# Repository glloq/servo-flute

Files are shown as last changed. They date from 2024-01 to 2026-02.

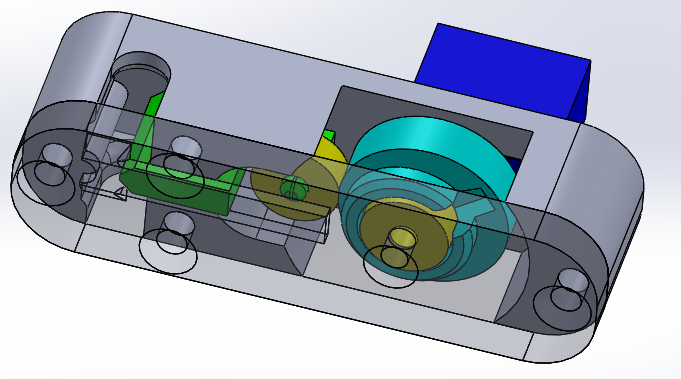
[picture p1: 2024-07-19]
img/servo vavle variable.png

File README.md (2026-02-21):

# Servo Flute V3 🎵

**Une flûte robotique contrôlée par MIDI avec support breath controller**





---

## 📋 Vue d'ensemble

La **Servo Flute V3** est un instrument robotique qui transforme des messages MIDI en sons de flûte acoustique. Utilisant des servomoteurs pour actionner les doigts et contrôler le débit d'air, elle offre un contrôle expressif comparable à une flûte jouée par un humain.

### Caractéristiques principales

- ✅ **Contrôle MIDI complet** - 8 Control Changes implémentés
- ✅ **Breath Controller (CC2)** - Contrôle dynamique du souffle en temps réel
- ✅ **Irish Flute 6 trous** - 14 notes jouables (A#5 - G7)
- ✅ **Vibrato optimisé** - sin() LUT pour CPU efficace
- ✅ **Watchdog timer** - Auto-restart en cas de blocage
- ✅ **Outil de calibration** - Interface Serial Monitor intuitive
- ✅ **Auto-calibration micro** - INMP441 I2S pour calibration airflow automatique
- ✅ **Documentation complète** - Architecture, MIDI, Configuration

---

## 🚀 Démarrage Rapide

### Matériel Requis
#### Electronique :
- un controleur tel que l'arduino leonardo ou micro et des cables de prototypage
- un module PCA9685
- 7 servomoteurs 9g bas de gamme (avec dent metalique) => 6 doigts et 1 servo air flow
- Alimentation 5V 5A minimum
- Un solenoide 5V/6V avec 2N min (ideal secutiré a 5N ) il faut viser 500mA maximum de consomation pour eviter la surchauffe (idéal autour de 300mA)
- un mofset adapté a la puissance
- une diode de roue libre
- un condensateur adapté
- (Optionnel) **Micro INMP441** I2S MEMS pour auto-calibration du debit d'air 
  
  #### Mécanique :
  
- un systeme de mousse a pores fermée environ 3mm d'epaisseur
- les doigts et supports imprimé en 3D
- servo valve imprimé en 3D avec 2 roulements 12x4x3 et 3vis/ecrous M3x20mm 
- une boite ou planche pour supportrer le tout 

## Premiere utilisation

#### Calibration 

avant de fixer les doigts, il faut que les servomoteur soit initialisé en position fermé a 90° 
Pour le servo AirFlow, il faut bien definir les 2 angles maximum de deplacement ( SERVO_VALVE_MIN_FLOW , SERVO_VALVE_MAX_FLOW ) en fonction du systeme utilisé

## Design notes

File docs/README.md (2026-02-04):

# Documentation Servo Flute V3

Bienvenue dans la documentation complète de la Servo Flute V3 - Une flûte robotique contrôlée par MIDI.

---

## 📚 Index de la Documentation

### 🏁 Démarrage

| Document | Description |
|---|---|
| **[README_V3.md](README_V3.md)** | Vue d'ensemble de la Servo Flute V3 |
| **[CONFIGURATION_GUIDE.md](CONFIGURATION_GUIDE.md)** | Guide de configuration complète |
| **[../Calibration_Tool/README.md](../Calibration_Tool/README.md)** | Guide d'utilisation de l'outil de calibration |

### 🏗️ Architecture et Code

| Document | Description |
|---|---|
| **[ARCHITECTURE.md](ARCHITECTURE.md)** | Architecture globale du système |
| | • Structure des classes |
| | • Flux de données |
| | • Organisation du code |
| | • Sécurité et robustesse |

### 🎹 MIDI et Contrôles

| Document | Description |
|---|---|
| **[MIDI_CC_IMPLEMENTATION.md](MIDI_CC_IMPLEMENTATION.md)** | Tous les Control Changes MIDI |
| | • CC1 (Modulation/Vibrato) |
| | • CC2 (Breath Controller) |
| | • CC7 (Volume) |
| | • CC11 (Expression) |
| | • CC74 (Brightness) |
| | • CC120, CC121, CC123 (Contrôles système) |
| | • Canal MIDI et rate limiting |
| **[CC2_BREATH_CONTROLLER.md](CC2_BREATH_CONTROLLER.md)** | CC2 Breath Controller détaillé |
| | • Fonctionnement technique |
| | • Configuration |
| | • Lissage, courbe exponentielle |
| | • Cas d'usage |
| | • Dépannage |

### ⚙️ Optimisations et Techniques

| Document | Description |
|---|---|
| **[SOLENOID_PWM.md](SOLENOID_PWM.md)** | Contrôle PWM du solénoïde |
| | • PWM activation + maintien |
| | • Réduction consommation |
| | • Durée de vie prolongée |
| **[VALVE_OPTIMIZATION.md](VALVE_OPTIMIZATION.md)** | Optimisation de la valve pneumatique |
| | • Temps de réponse |
| | • Gestion transitions |
| **[TIMING_ANTICIPATION.md](TIMING_ANTICIPATION.md)** | Timing et anticipation mécanique |
| | • Anticipation doigts |
| | • Séquençage événements |
| | • Legato et staccato |

### 🎼 Instruments

| Document | Description |
|---|---|
| **[INSTRUMENTS_GUIDE.md](INSTRUMENTS_GUIDE.md)** | Guide pour différents instruments |
| | • Irish Flute (6 trous) |
| | • Flûte à bec |
| | • Adaptation personnalisée |

---

## 🎯 Parcours Recommandés

### Pour débutant (première utilisation)

1. **[README_V3.md](README_V3.md)** - Comprendre le projet
2. **[CONFIGURATION_GUIDE.md](CONFIGURATION_GUIDE.md)** - Configuration matérielle
3. **[../Calibration_Tool/README.md](../Calibration_Tool/README.md)** - Calibrer l'instrument
4. **[MIDI_CC_IMPLEMENTATION.md](MIDI_CC_IMPLEMENTATION.md)** - Découvrir les contrôles MIDI

### Pour développeur (comprendre le code)

1. **[ARCHITECTURE.md](ARCHITECTURE.md)** - Structure globale
2. **[MIDI_CC_IMPLEMENTATION.md](MIDI_CC_IMPLEMENTATION.md)** - Implémentation MIDI
3. **[CC2_BREATH_CONTROLLER.md](CC2_BREATH_CONTROLLER.md)** - Feature avancée CC2
4. **[TIMING_ANTICIPATION.md](TIMING_ANTICIPATION.md)** - Timing précis

### Pour musicien (utilisation avancée)

1. **[MIDI_CC_IMPLEMENTATION.md](MIDI_CC_IMPLEMENTATION.md)** - Tous les contrôles MIDI
2. **[CC2_BREATH_CONTROLLER.md](CC2_BREATH_CONTROLLER.md)** - Breath controller physique
3. **[INSTRUMENTS_GUIDE.md](INSTRUMENTS_GUIDE.md)** - Adapter à votre instrument

### Pour optimisation et troubleshooting

1. **[SOLENOID_PWM.md](SOLENOID_PWM.md)** - Optimisation solénoïde
2. **[VALVE_OPTIMIZATION.md](VALVE_OPTIMIZATION.md)** - Optimisation valve
3. **[TIMING_ANTICIPATION.md](TIMING_ANTICIPATION.md)** - Réglages timing

---

## 🔧 Configuration Actuelle

**Instrument :** Irish Flute 6 trous
**Tonalité :** C majeur
**Notes jouables :** 14 (A#5 - G7)
**Servos doigts :** 6
**Canal MIDI :** Omni (0) - Écoute tous les canaux

---

## 🎵 Features MIDI Implémentées

### Control Changes (CC)

- ✅ **CC1** - Modulation (Vibrato)
- ✅ **CC2** - Breath Controller (Contrôle dynamique souffle)
- ✅ **CC7** - Volume (Réduction limite haute)
- ✅ **CC11** - Expression (Nuances dynamiques)
- ✅ **CC74** - Brightness (Stocké, usage futur)
- ✅ **CC120** - All Sound Off (Arrêt urgence)
- ✅ **CC121** - Reset All Controllers
- ✅ **CC123** - All Notes Off

### Autres Features MIDI

- ✅ **Canal MIDI** : Omni mode (0) ou spécifique (1-16)
- ✅ **Rate Limiting** : 10 CC/sec général, 50 CC2/sec
- ✅ **Vibrato optimisé** : sin() LUT 256 entrées
- ❌ **Pitch Bend** : Retiré (logique incorrecte)

---

## 📊 Ordre d'Application des Contrôles

```
CC7 (Volume) → CC2 (Breath) OU Velocity → CC11 (Expression) → CC1 (Vibrato)
      ↓                 ↓                        ↓                   ↓
 Réduit plage      Source airflow           Nuances dans      Oscillation
 haute globale     (choix prioritaire)      plage réduite     autour angle
```

**Détails :** Voir [MIDI_CC_IMPLEMENTATION.md](MIDI_CC_IMPLEMENTATION.md)

---

## 🛠️ Outils Disponibles

### Calibration Tool

**Emplacement :** `/Calibration_Tool/`

**Fonction :** Calibration interactive via Serial Monitor

**Workflow :**
1. Calibrer servos doigts (angle + direction)
2. Calibrer notes (airflowMin% + airflowMax%)
3. Générer code C++ formaté
4. Copier-coller dans `settings.h`

**Documentation :** [../Calibration_Tool/README.md](../Calibration_Tool/README.md)

---

## 🔒 Sécurité

### Watchdog Timer
- **Timeout :** 4 secondes
- **Fonction :** Auto-restart si code bloqué
- **Implémentation :** `wdt_enable(WDTO_4S)` + `wdt_reset()` dans loop

### État Sûr (initSafeState)
- **Appelé :** Au démarrage AVANT toute initialisation
- **Actions :** Solénoïde fermé, airflow repos, doigts fermés
- **Protection :** Crash, reset, power-on

### Rate Limiting
- **CC général :** 10 messages/sec
- **CC2 (Breath) :** 50 messages/sec
- **Exemptions :** CC 120, 121, 123 (urgence)

---

## 📈 Historique des Versions

### V3 (Actuelle)

**Date :** 2026-01-25 à 2026-02-04

**Features majeures :**
- ✅ Control Changes MIDI complets (8 CC)
- ✅ CC2 Breath Controller (contrôle souffle dynamique)
- ✅ Nouvelle logique CC7→CC2→CC11
- ✅ Rate limiting configurableble
- ✅ Canal MIDI (omni + spécifique)
- ✅ Vibrato optimisé (sin LUT)
- ✅ Watchdog timer + état sûr
- ✅ Configuration Irish Flute 6 trous
- ✅ Outil calibration standalone

**Commits principaux :**
- `CC2 Breath Controller : Contrôle dynamique souffle` (2026-02-04)
- `Suppression Pitch Bend : Logique incorrecte retirée` (2026-02-04)
- `Nouvelle logique CC7/CC11 : Volume réduit plage avant Expression` (2026-02-04)
- `Améliorations MIDI : Canal, CC étendus, Rate Limiting` (2026-02-04)

---

## 🤝 Contribution

### Structure Documentation

**Principe :** Un document = Un sujet précis

**Organisation :**
```
docs/
├── README.md                      # Index (ce fichier)
├── ARCHITECTURE.md                # Architecture code
├── MIDI_CC_IMPLEMENTATION.md      # Control Changes généraux
├── CC2_BREATH_CONTROLLER.md       # CC2 spécifique (détaillé)
├── CONFIGURATION_GUIDE.md         # Configuration matérielle
├── INSTRUMENTS_GUIDE.md           # Adaptation instruments
├── SOLENOID_PWM.md                # Technique solénoïde
├── TIMING_ANTICIPATION.md         # Technique timing
├── VALVE_OPTIMIZATION.md          # Optimisation valve
└── README_V3.md                   # Vue d'ensemble V3
```

**Ajout de documentation :**
1. Créer document dans `/docs/`
2. Format Markdown
3. Mettre à jour cet index (README.md)
4. Commit avec message descriptif

---

## 📞 Support

**GitHub Repository :** [https://github.com/glloq/servo-flute](https://github.com/glloq/servo-flute)

**Issues :** Utiliser GitHub Issues pour :
- Bugs
- Questions
- Suggestions d'amélioration
- Demandes de documentation

---

**Créé le :** 2026-02-04
**Version Servo Flute :** V3
**Dernière mise à jour :** 2026-02-04

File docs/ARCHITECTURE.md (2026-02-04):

# Architecture Servo Flute V3

## 📋 Vue d'ensemble

La Servo Flute V3 est une flûte robotique contrôlée par MIDI, utilisant des servomoteurs pour actionner les doigts et contrôler le débit d'air. L'architecture est modulaire, séparant les responsabilités en classes spécialisées.

**Version :** V3
**Platform

e :** Arduino (ATmega32u4 - Leonardo/Micro)
**Date :** 2026-02-04

---

## 🏗️ Structure des dossiers

```
servo-flute/
├── Servo_flute_v3/           # Code principal Arduino
│   ├── Servo_flute_v3.ino    # Sketch principal
│   ├── settings.h            # Configuration (CENTRAL)
│   ├── MidiHandler.h/cpp     # Réception MIDI
│   ├── InstrumentManager.h/cpp  # Orchestration globale
│   ├── AirflowController.h/cpp  # Contrôle airflow + CC
│   ├── FingerController.h/cpp   # Contrôle doigts
│   ├── NoteSequencer.h/cpp      # Séquençage notes
│   └── EventQueue.h/cpp         # File d'événements MIDI
│
├── Calibration_Tool/         # Outil calibration standalone
│   ├── Calibration_Tool.ino
│   ├── settings_template.h
│   ├── CalibrationManager.h/cpp
│   ├── FingerCalibrator.h/cpp
│   ├── AirflowCalibrator.h/cpp
│   ├── OutputGenerator.h/cpp
│   └── README.md
│
├── docs/                     # Documentation
│   ├── ARCHITECTURE.md       # Ce fichier
│   ├── MIDI_CC_IMPLEMENTATION.md
│   ├── CC2_BREATH_CONTROLLER.md
│   ├── CONFIGURATION_GUIDE.md
│   ├── INSTRUMENTS_GUIDE.md
│   ├── SOLENOID_PWM.md
│   ├── TIMING_ANTICIPATION.md
│   ├── VALVE_OPTIMIZATION.md
│   └── README_V3.md
│
├── img/                      # Images
├── stl/                      # Fichiers STL (mécanique)
└── README.md                 # Documentation principale
```

---

## 🔧 Classes principales

### 1. **Servo_flute_v3.ino** - Sketch principal

**Rôle :** Point d'entrée, boucle principale, watchdog

**Responsabilités :**
- Initialisation matériel (`setup()`)
- Boucle principale (`loop()`)
- Watchdog timer (4s, auto-restart)
- État sûr en cas de crash (`initSafeState()`)

**Code clé :**
```cpp
void setup() {
  initSafeState();           // État sûr AVANT tout
  wdt_enable(WDTO_4S);       // Watchdog 4 secondes
  instrumentManager.begin(); // Initialiser tout
}

void loop() {
  wdt_reset();                      // Reset watchdog
  instrumentManager.processMidi();  // Traiter MIDI
  instrumentManager.update();       // Mise à jour contrôles
}
```

---

### 2. **settings.h** - Configuration centrale

**Rôle :** TOUTES les constantes du projet (un seul endroit)

**Sections :**
```cpp
// Hardware
#define NUMBER_SERVOS_FINGER 6
#define SERVO_FREQUENCY 50
#define SOLENOID_PIN 13

// Notes jouables (Irish flute 6 trous)
const NoteDefinition NOTES[] = { ... };

// MIDI
#define MIDI_CHANNEL 0
#define CC_RATE_LIMIT_PER_SECOND 10

// CC2 Breath Controller
#define CC2_ENABLED true
#define CC2_RATE_LIMIT_PER_SECOND 50
#define CC2_SMOOTHING_BUFFER_SIZE 5
// ...

// Vibrato
#define VIBRATO_FREQUENCY_HZ 6.0
#define VIBRATO_MAX_AMPLITUDE_DEG 8.0

// Debug
#define DEBUG 0
```

**Avantages :**
- Un seul fichier à modifier pour configuration
- Pas de magic numbers dans le code
- Facilite portage vers autres instruments

---

### 3. **MidiHandler** - Réception MIDI

**Rôle :** Écoute USB MIDI, filtre canaux, dispatch messages

**Fichiers :** `MidiHandler.h/cpp`

**Responsabilités :**
- Lire messages USB MIDI (`MIDIUSB.read()`)
- Filtrer par canal MIDI (omni ou spécifique)
- Parser messages (Note On/Off, CC, etc.)
- Déléguer à InstrumentManager

**Flux :**
```
USB MIDI → MidiHandler.processMidi()
              ↓
         isChannelAccepted()?
              ↓ (oui)
         Switch (messageType)
              ↓
    0x90 → instrument.noteOn()
    0x80 → instrument.noteOff()
    0xB0 → instrument.handleControlChange()
```

**Code clé :**
```cpp
void MidiHandler::processMidi() {
  midiEventPacket_t midiEvent = MidiUSB.read();

  byte channel = midiEvent.byte1 & 0x0F;
  if (!isChannelAccepted(channel)) return;  // Filtrage canal

  byte messageType = midiEvent.byte1 & 0xF0;

  switch (messageType) {
    case 0x90:  // Note On
      _instrument.noteOn(note, velocity);
      break;
    case 0xB0:  // Control Change
      _instrument.handleControlChange(ccNumber, ccValue);
      break;
  }
}
```

---

### 4. **InstrumentManager** - Chef d'orchestre

**Rôle :** Gestion globale, coordination entre tous les composants

**Fichiers :** `InstrumentManager.h/cpp`

**Responsabilités :**
- Initialiser tous les contrôleurs
- Gérer queue d'événements MIDI
- Gérer Control Changes (rate limiting, stockage)
- Coordonner FingerController + AirflowController + NoteSequencer
- Power management servos

**Sous-composants :**
```cpp
class InstrumentManager {
  Adafruit_PWMServoDriver _pwm;      // Driver PCA9685
  EventQueue _eventQueue;            // File MIDI
  FingerController _fingerCtrl;      // Contrôle doigts
  AirflowController _airflowCtrl;    // Contrôle airflow
  NoteSequencer _sequencer;          // Séquenceur

  // CC MIDI
  byte _ccVolume, _ccExpression, _ccModulation, _ccBreath, _ccBrightness;

  // Rate limiting
  uint16_t _ccCount, _cc2Count;
  unsigned long _ccWindowStart, _cc2WindowStart;
};
```

**Méthodes principales :**
```cpp
void begin();                              // Initialisation
void processMidi();                        // Traiter messages MIDI
void update();                             // Mise à jour continue
void noteOn(byte note, byte velocity);     // Note On
void noteOff(byte note);                   // Note Off
void handleControlChange(byte cc, byte val); // CC MIDI
void allSoundOff();                        // Urgence
void resetAllControllers();                // Reset CC
```

---

### 5. **AirflowController** - Contrôle du souffle

**Rôle :** Gérer servo airflow + solénoïde + tous les CC

**Fichiers :** `AirflowController.h/cpp`

**Responsabilités :**
- Positionner servo airflow selon note + velocity/CC2
- Contrôler solénoïde (ouverture/fermeture valve)
- Appliquer CC7 (Volume), CC2 (Breath), CC11 (Expression)
- Gérer vibrato (CC1)
- Lissage CC2 (buffer circulaire)
- Fallback velocity si CC2 absent

**Variables clés :**
```cpp
byte _ccVolume, _ccExpression, _ccModulation, _ccBreath;

// CC2 Breath Controller
byte _cc2SmoothingBuffer[5];
uint8_t _cc2BufferIndex, _cc2BufferCount;
unsigned long _lastCC2Time;
byte _lastVelocity;

// Vibrato
uint16_t _baseAngleWithoutVibrato;
bool _vibratoActive;
uint16_t _currentMinAngle, _currentMaxAngle;
```

**Méthodes principales :**
```cpp
void setAirflowForNote(byte note, byte velocity);  // Calcul angle note
void setCCValues(byte cc7, byte cc11, byte cc1);   // Mise à jour CC
void updateCC2Breath(byte cc2);                    // Recevoir CC2
void openSolenoid();                               // Ouvrir valve
void closeSolenoid();                              // Fermer valve
void update();                                     // Appliquer vibrato
```

**Ordre application (setAirflowForNote) :**
```
1. CC7 (Volume) → Réduit effectiveMaxAngle
2. CC2 (Breath) OU Velocity → Définit baseAngle
   - Si CC2 actif : moyenne lissée, courbe expo, seuil silence
   - Sinon : velocity classique
3. CC11 (Expression) → Module dans [minAngle, baseAngle]
4. Limiter bornes [SERVO_AIRFLOW_MIN, SERVO_AIRFLOW_MAX]
5. Stocker _baseAngleWithoutVibrato
6. CC1 (Vibrato) → Appliqué dans update() (continu)
```

---

### 6. **FingerController** - Contrôle des doigts

**Rôle :** Actionner servos doigts pour former les notes

**Fichiers :** `FingerController.h/cpp`

**Responsabilités :**
- Positionner servos doigts (ouvert/fermé)
- Gérer configuration par note (tableau NOTES[])
- Supporter inversion de sens servo

**Méthode principale :**
```cpp
void setFingersForNote(byte midiNote) {
  const NoteDefinition* note = getNoteByMidi(midiNote);

  for (int i = 0; i < NUMBER_SERVOS_FINGER; i++) {
    if (note->fingersClosed & (1 << i)) {
      // Doigt fermé
      setServoAngle(i, FINGERS[i].closedAngle);
    } else {
      // Doigt ouvert
      setServoAngle(i, FINGERS[i].openAngle);
    }
  }
}
```

**Configuration doigt (settings.h) :**
```cpp
const FingerDefinition FINGERS[] = {
  {0, 90, false},  // Servo 0: fermé=0°, ouvert=90°, pas inversé
  {0, 90, false},  // Servo 1
  {0, 90, false},  // Servo 2
  {0, 90, false},  // Servo 3
  {0, 90, false},  // Servo 4
  {0, 90, false}   // Servo 5
};
```

---

### 7. **NoteSequencer** - Séquençage temporel

**Rôle :** Gérer timing des événements, anticipation mécanique

**Fichiers :** `NoteSequencer.h/cpp`

**Responsabilités :**
- Anticiper mouvements mécaniques (doigts avant airflow)
- Gérer transitions entre notes (legato/staccato)
- Queue d'événements futurs
- Timing précis (ms)

**Constantes timing (settings.h) :**
```cpp
#define NOTE_ON_ANTICIPATION_TIME 30     // 30ms avant ouverture valve
#define NOTE_OFF_DELAY_TIME 10           // 10ms après fermeture valve
#define LEGATO_DELAY 20                  // 20ms pour legato
```

**Flux Note On :**
```
t=0ms   : noteOn() appelé
t=0ms   : Doigts positionnés
t=30ms  : Valve ouverte + Airflow activé  (anticipation)
```

**Flux Note Off :**
```
t=0ms   : noteOff() appelé
t=0ms   : Valve fermée + Airflow coupé
t=10ms  : Doigts libérés  (délai)
```

---

### 8. **EventQueue** - File d'événements

**Rôle :** Queue FIFO pour événements MIDI avec timestamp

**Fichiers :** `EventQueue.h/cpp`

**Structure :**
```cpp
struct Event {
  unsigned long timestamp;   // Quand exécuter (ms)
  byte type;                 // NOTE_ON, NOTE_OFF, etc.
  byte note;
  byte velocity;
};
```

**Méthodes :**
```cpp
bool push(Event event);       // Ajouter événement
bool pop(Event& event);       // Retirer événement
Event* peek();                // Voir prochain
bool isEmpty();
void clear();                 // Vider
```

---

## 🔄 Flux de données

### Flux complet Note On

```
1. USB MIDI Note On reçu
         ↓
2. MidiHandler.processMidi()
   - Lecture MIDIUSB.read()
   - Filtrage canal MIDI
         ↓
3. InstrumentManager.noteOn(note, velocity)
   - Ajouter événement à EventQueue
   - Timestamp = now + anticipation
         ↓
4. NoteSequencer.update() (dans loop)
   - Événement prêt ?
         ↓
5. FingerController.setFingersForNote(note)
   - Positionner servos doigts
         ↓
6. AirflowController.setAirflowForNote(note, velocity)
   - Calcul angle : CC7 → CC2/Velocity → CC11
   - Stocker _baseAngleWithoutVibrato
         ↓
7. AirflowController.openSolenoid()
   - Ouvrir valve pneumatique
         ↓
8. AirflowController.update() (continu dans loop)
   - Si CC1 > 0 : Appliquer vibrato
   - Sin() LUT pour oscillation
   - Limiter [_currentMinAngle, _currentMaxAngle]
```

### Flux Control Change (CC2 Breath)

```
1. USB MIDI CC2 reçu (valeur 0-127)
         ↓
2. MidiHandler.processMidi()
   - case 0xB0: Control Change
         ↓
3. InstrumentManager.handleControlChange(2, ccValue)
   - Rate limiting vérifié (50/sec max pour CC2)
         ↓
4. AirflowController.updateCC2Breath(ccValue)
   - Ajouter au buffer circulaire
   - Mise à jour _lastCC2Time
         ↓
5. Prochaine note jouée → setAirflowForNote()
   - Vérifier timeout CC2
   - Calculer moyenne lissée buffer
   - Appliquer courbe exponentielle
   - Vérifier seuil silence
   - Utiliser CC2 comme airflowSource (remplace velocity)
         ↓
6. Angle airflow calculé avec CC2 au lieu de velocity
```

---

## 🎛️ Configuration par instrument

### Irish Flute (6 trous) - Configuration actuelle

**settings.h :**
```cpp
#define NUMBER_SERVOS_FINGER 6

const NoteDefinition NOTES[] = {
  // midiNote, airflowMin%, airflowMax%, fingersBitmap
  {70,  20,  75, 0b111111},  // A#5 (tous fermés)
  {72,  20,  75, 0b111110},  // C6
  {73,  20,  75, 0b111100},  // C#6
  {74,  25,  70, 0b111000},  // D6
  {75,  25,  70, 0b110000},  // D#6
  {77,  25,  70, 0b100000},  // F6
  {78,  30,  65, 0b000000},  // F#6 (tous ouverts)
  // ... octave supérieur
  {91,  40,  55, 0b000000}   // G7
};
```

**Caractéristiques :**
- 6 servos doigts
- 14 notes jouables (A#5 - G7)
- Tonalité : C majeur
- Airflow : 20-75% (notes graves), 40-55% (notes aiguës)

### Adaptation pour autre instrument

**Exemple : Flûte à bec soprano (8 trous)**

```cpp
#define NUMBER_SERVOS_FINGER 8  // Au lieu de 6

const NoteDefinition NOTES[] = {
  {67,  15,  80, 0b11111111},  // G4 (tous fermés)
  {69,  15,  80, 0b11111110},  // A4
  // ... définir toutes les notes
  {86,  50,  60, 0b00000000}   // D6 (tous ouverts)
};

const FingerDefinition FINGERS[] = {
  {0, 90, false},  // 8 servos au lieu de 6
  {0, 90, false},
  {0, 90, false},
  {0, 90, false},
  {0, 90, false},
  {0, 90, false},
  {0, 90, false},
  {0, 90, false}
};
```

**Le code s'adapte automatiquement** grâce à `NUMBER_SERVOS_FINGER` !

---

## 🔒 Sécurité et robustesse

### 1. Watchdog Timer

**Problème :** Code bloqué (bug, boucle infinie) → Instrument mort

**Solution :** Watchdog 4 secondes auto-restart

```cpp
// setup()
wdt_enable(WDTO_4S);  // Watchdog 4 secondes

// loop()
wdt_reset();  // Reset à chaque itération
```

Si `loop()` ne s'exécute pas pendant 4s → Arduino redémarre automatiquement

### 2. État sûr (initSafeState)

**Problème :** Crash, reset, power-on → Servos position inconnue

**Solution :** État sûr AVANT tout

```cpp
void initSafeState() {
  // Fermer solénoïde
  digitalWrite(SOLENOID_PIN, LOW);

  // Airflow au repos
  pwm.setPWM(NUM_SERVO_AIRFLOW, 0, pulseWidthOff);

  // Tous doigts fermés
  for (int i = 0; i < NUMBER_SERVOS_FINGER; i++) {
    pwm.setPWM(i, 0, pulseWidthClosed);
  }
}
```

Appelé en **PREMIER** dans `setup()`, avant toute autre init.

### 3. Rate Limiting

**Problème :** Flood MIDI → Saturation CPU, jitter servos

**Solution :** Limite 10 CC/sec (50 CC2/sec)

```cpp
if (_ccCount > CC_RATE_LIMIT_PER_SECOND) {
  return;  // Ignorer message
}
```

Messages urgents (CC 120, 121, 123) exemptés.

### 4. Validation entrées

**Problème :** Valeurs MIDI invalides (>127, négatives)

**Solution :** Validation systématique

```cpp
if (ccValue > 127) {
  if (DEBUG) Serial.println("ERREUR: CC invalide");
  return;  // Ignorer
}
```

### 5. Bornes servos

**Problème :** Angle calculé hors bornes physiques → Dommages mécanique

**Solution :** Clamp systématique

```cpp
if (finalAngle < SERVO_AIRFLOW_MIN) finalAngle = SERVO_AIRFLOW_MIN;
if (finalAngle > SERVO_AIRFLOW_MAX) finalAngle = SERVO_AIRFLOW_MAX;
```

Garanti servo toujours dans plage valide.

---

## 📊 Performance

### Temps de réponse

| Événement | Latence | Note |
|---|---|---|
| Note On → Doigts positionnés | < 5ms | Instantané |
| Note On → Valve ouverte | 30ms | Anticipation intentionnelle |
| CC2 reçu → Airflow ajusté | < 2ms | Très réactif |
| Vibrato update | 1ms | Continu (loop) |

### Charge CPU

| Tâche | CPU | Note |
|---|-----|---|
| Loop principale | ~20% | Léger |
| Rate limiting | < 1% | Négligeable |
| CC2 lissage | ~2% | Buffer moyennage |
| Vibrato sin() LUT | < 1% | Optimisé PROGMEM |
| **Total** | **~25%** | **Marge confortable** |

### Optimisations

1. **Sin() Lookup Table** : 256 entrées PROGMEM → 25x plus rapide que `sin()`
2. **Rate limiting** : Évite surcharge inutile
3. **Buffer circulaire CC2** : Moyenne glissante efficace
4. **Anticipation mécanique** : Masque latence doigts

---

## 🛠️ Outils de développement

### Calibration Tool

**Emplacement :** `/Calibration_Tool/`

**Rôle :** Calibrer servos doigts + airflow par note

**Workflow :**
1. Lancer `Calibration_Tool.ino`
2. Calibrer servos (angle fermé + ouvert)
3. Calibrer notes (airflowMin% + airflowMax%)
4. Générer code C++ formaté
5. Copier-coller dans `settings.h`

**Avantages :**
- Interface Serial Monitor intuitive
- Génère code prêt à l'emploi
- Évite erreurs manuelles

**Documentation :** Voir `/Calibration_Tool/README.md`

---

## 📚 Documentation associée

- **[MIDI_CC_IMPLEMENTATION.md](MIDI_CC_IMPLEMENTATION.md)** - Tous les Control Changes
- **[CC2_BREATH_CONTROLLER.md](CC2_BREATH_CONTROLLER.md)** - CC2 Breath Controller détaillé
- **[CONFIGURATION_GUIDE.md](CONFIGURATION_GUIDE.md)** - Guide configuration complète
- **[INSTRUMENTS_GUIDE.md](INSTRUMENTS_GUIDE.md)** - Adaptation autres instruments
- **[SOLENOID_PWM.md](SOLENOID_PWM.md)** - Contrôle PWM solénoïde
- **[TIMING_ANTICIPATION.md](TIMING_ANTICIPATION.md)** - Timing et anticipation
- **[VALVE_OPTIMIZATION.md](VALVE_OPTIMIZATION.md)** - Optimisation valve
- **[README_V3.md](README_V3.md)** - Vue d'ensemble V3

---

**Créé le :** 2026-02-04
**Version Servo Flute :** V3
**Statut :** ✅ Production

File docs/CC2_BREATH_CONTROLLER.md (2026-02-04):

# CC2 Breath Controller - Contrôle Dynamique du Souffle

## 📋 Vue d'ensemble

Le **CC2 (Breath Controller)** permet un contrôle dynamique et expressif du souffle en temps réel sur la servo-flute. Il remplace la velocity MIDI pour offrir un contrôle continu de l'airflow, transformant la servo-flute en véritable instrument à vent MIDI jouable avec un breath controller physique ou via automation DAW.

**Implémentation :** Option 1 - Remplacement Velocity
**Date d'implémentation :** 2026-02-04
**Statut :** ✅ Complet et fonctionnel

---

## 🎯 Qu'est-ce qu'un Breath Controller ?

### Définition

Un breath controller est un capteur de pression buccale qui convertit l'intensité du souffle d'un musicien en messages MIDI CC2 (valeurs 0-127). Il permet de contrôler des instruments MIDI comme on soufflerait dans un instrument à vent acoustique.

### Contrôleurs physiques compatibles

- **Yamaha BC3A / BC3** : Capteur de pression avec tube
- **TEControl BBC2** : Breath controller USB moderne
- **AKAI EWI / Yamaha WX5** : Wind controllers avec capteur intégré
- **Automation DAW** : Courbes de souffle dessinées (Ableton, Logic, etc.)

---

## 🔧 Fonctionnement Technique

### Principe de base

```
Musicien souffle → Capteur pression → CC2 MIDI (0-127) → Servo-flute → Airflow dynamique
```

**Différence avec Velocity :**
- **Velocity** : Fixe, définie au Note On (une seule valeur par note)
- **CC2** : Continu, envoyé en temps réel (20-100 msg/sec pendant la note)

### Ordre d'application

```
CC7 (Volume) → CC2 (Breath) OU Velocity → CC11 (Expression) → CC1 (Vibrato)
         ↓              ↓                        ↓                    ↓
   Réduit plage    Source airflow         Nuances dans      Oscillation
   haute globale   principale (choix)     plage réduite     autour angle
```

---

## ⚙️ Configuration (settings.h)

### Constantes disponibles

```cpp
/*******************************************************************************
--------------------  BREATH CONTROLLER (CC2) SETTINGS  ----------------------
******************************************************************************/

#define CC2_ENABLED true                  // Activer/désactiver CC2
#define CC2_RATE_LIMIT_PER_SECOND 50      // Max 50 CC2/sec (haute fréquence)
#define CC2_SILENCE_THRESHOLD 10          // CC2 < 10 → valve fermée
#define CC2_SMOOTHING_BUFFER_SIZE 5       // Buffer lissage (moyenne glissante)
#define CC2_RESPONSE_CURVE 1.4            // Courbe exponentielle (1.0-2.0)
#define CC2_TIMEOUT_MS 1000               // Timeout fallback velocity (ms)
```

### Paramètres expliqués

#### CC2_ENABLED
- **Type :** `true` / `false`
- **Défaut :** `true`
- **Effet :** Active ou désactive complètement le breath controller
- **Usage :** Mettre à `false` pour revenir au comportement velocity classique

#### CC2_RATE_LIMIT_PER_SECOND
- **Type :** Entier (1-100)
- **Défaut :** `50`
- **Effet :** Nombre maximum de messages CC2 traités par seconde
- **Recommandations :**
  - **30** : Automation DAW légère
  - **50** : Breath controller physique standard (défaut)
  - **100** : Breath controller haute performance (peut créer jitter)

#### CC2_SILENCE_THRESHOLD
- **Type :** Entier (0-127)
- **Défaut :** `10`
- **Effet :** Valeurs CC2 < seuil → considérées comme silence (valve fermée)
- **Recommandations :**
  - **5** : Seuil très bas (capte souffle très faible)
  - **10** : Seuil standard (défaut, évite bruits parasites)
  - **20** : Seuil élevé (nécessite souffle plus fort pour déclencher)

#### CC2_SMOOTHING_BUFFER_SIZE
- **Type :** Entier (1-10)
- **Défaut :** `5`
- **Effet :** Taille du buffer de lissage (moyenne glissante)
- **Recommandations :**
  - **3** : Lissage léger, réponse très rapide (peut avoir jitter)
  - **5** : Lissage standard (défaut, bon compromis)
  - **7-10** : Lissage fort, réponse plus lente mais très stable

#### CC2_RESPONSE_CURVE
- **Type :** Float (1.0-2.0)
- **Défaut :** `1.4`
- **Effet :** Courbe exponentielle appliquée : `CC2^valeur`
- **Comportement :**
  - **1.0** : Linéaire (pas de courbe)
  - **1.2-1.4** : Légèrement exponentiel (souffle faible = contrôle fin)
  - **1.5-1.8** : Très exponentiel (souffle faible = beaucoup de contrôle)
  - **2.0** : Quadratique (souffle faible = maximum de contrôle)

**Exemple courbe 1.4 :**
```
CC2 raw → Après courbe
10 → 6     (souffle faible = contrôle très fin)
50 → 35    (souffle moyen = contrôle progressif)
100 → 83   (souffle fort = puissance)
127 → 127  (souffle max = max)
```

#### CC2_TIMEOUT_MS
- **Type :** Entier (0-5000 ms)
- **Défaut :** `1000` (1 seconde)
- **Effet :** Temps sans CC2 avant fallback sur velocity
- **Recommandations :**
  - **0** : Pas de timeout (toujours CC2 si reçu, sinon velocity)
  - **500** : Timeout court (fallback rapide)
  - **1000** : Timeout standard (défaut)
  - **2000+** : Timeout long (breath controller temporairement inactif OK)

---

## 🎵 Fonctionnalités

### 1. Lissage (Smoothing)

**Problème :** Les breath controllers envoient des données très rapidement (50-100/sec) avec micro-variations → Jitter du servo

**Solution :** Buffer circulaire avec moyenne glissante

```cpp
// Buffer circulaire de 5 valeurs (défaut)
byte _cc2SmoothingBuffer[5] = {120, 122, 121, 123, 122};

// Calcul moyenne
smoothedCC2 = (120 + 122 + 121 + 123 + 122) / 5 = 121.6 ≈ 122

// Nouvelle valeur reçue (124) → Remplace la plus ancienne
_cc2SmoothingBuffer = {122, 121, 123, 122, 124};
smoothedCC2 = 122.4 ≈ 122
```

**Avantages :**
- Élimine les micro-variations
- Servo suit doucement les changements
- Pas de saccades mécaniques

### 2. Courbe Exponentielle

**Problème :** Relation linéaire CC2 → airflow peu naturelle

**Solution :** Courbe exponentielle `CC2^1.4`

```cpp
float normalizedCC2 = smoothedCC2 / 127.0;     // 0.0 - 1.0
float curvedCC2 = pow(normalizedCC2, 1.4);     // Courbe exponentielle
byte finalCC2 = curvedCC2 * 127;               // Retour 0-127
```

**Effet musical :**

| CC2 raw | Après courbe | Commentaire |
|---|---|---|
| 20 | 11 | Souffle faible = GRAND contrôle fin |
| 40 | 26 | Contrôle progressif |
| 60 | 43 | Zone intermédiaire |
| 80 | 62 | Souffle fort commence |
| 100 | 83 | Puissance |
| 127 | 127 | Maximum inchangé |

**Avantages :**
- Souffle faible → Contrôle très précis (nuances pianissimo)
- Souffle fort → Puissance directe (fortissimo)
- Comportement naturel comme une vraie flûte

### 3. Seuil de Silence

**Problème :** CC2 = 0-9 → Bruits parasites, souffle trop faible

**Solution :** Seuil à 10 (configurable)

```cpp
if (smoothedCC2 < CC2_SILENCE_THRESHOLD) {
  airflowSource = 0;                    // Silence
  setAirflowServoAngle(SERVO_AIRFLOW_OFF);
  closeSolenoid();                      // Fermer valve
  return;
}
```

**Avantages :**
- Pas de bruits parasites avec souffle très faible
- Silence franc (valve fermée)
- Comportement naturel : pas de souffle = pas de son

### 4. Fallback Velocity

**Problème :** Breath controller déconnecté/absent → Aucun son

**Solution :** Timeout automatique avec fallback sur velocity

```cpp
unsigned long timeSinceCC2 = millis() - _lastCC2Time;

if (CC2_TIMEOUT_MS > 0 && timeSinceCC2 > CC2_TIMEOUT_MS) {
  // Timeout : fallback sur velocity
  airflowSource = velocity;

  if (DEBUG) {
    Serial.print("DEBUG: CC2 timeout (");
    Serial.print(timeSinceCC2);
    Serial.print("ms) - Fallback velocity");
  }
}
```

**Avantages :**
- Fonctionne sans breath controller (utilise velocity classique)
- Transition automatique transparente
- Utile si breath controller temporairement inactif

### 5. Rate Limiting Séparé

**Problème :** CC2 haute fréquence (50/sec) vs autres CC (10/sec)

**Solution :** Rate limit séparé pour CC2

```cpp
// InstrumentManager.cpp
if (ccNumber == 2) {
  // Rate limiting CC2 : 50 msg/sec
  if (_cc2Count > CC2_RATE_LIMIT_PER_SECOND) {
    return;  // Ignorer
  }
} else {
  // Rate limiting autres CC : 10 msg/sec
  if (_ccCount > CC_RATE_LIMIT_PER_SECOND) {
    return;  // Ignorer
  }
}
```

**Avantages :**
- CC2 peut envoyer 50/sec (haute fréquence nécessaire)
- Autres CC limités à 10/sec (suffisant)
- Protection CPU optimale

---

## 🎹 Cas d'usage

### Cas 1 : Musicien avec breath controller physique

**Setup :**
```
Yamaha BC3 → USB-MIDI → DAW → Servo-flute
```

**Comportement :**
1. Musicien joue note C6 (Note On, velocity 100)
2. Velocity donne attaque initiale → Angle de base
3. Musicien commence à souffler → CC2 reçu (20/sec)
4. CC2 remplace velocity immédiatement
5. Musicien module souffle en temps réel :
   - Souffle faible (CC2 = 30) → Son doux, contrôle fin
   - Souffle moyen (CC2 = 70) → Son normal
   - Souffle fort (CC2 = 120) → Son puissant
6. Crescendo/diminuendo naturels par pression buccale

**Résultat :** La servo-flute répond exactement comme si le musicien soufflait dedans directement !

### Cas 2 : Automation DAW sans breath controller

**Setup :**
```
Ableton Live → Automation CC2 dessinée → Servo-flute
```

**Comportement :**
1. DAW envoie Note On + CC2 automatisé (courbe dessinée)
2. CC2 simule courbe de souffle réaliste :
   - Attaque : CC2 monte de 0 → 100 (0.1s)
   - Sustain : CC2 varie 90-110 (vibrations naturelles)
   - Release : CC2 descend de 100 → 0 (0.2s)
3. Servo suit précisément la courbe automatisée

**Résultat :** Performance enregistrée avec dynamique de souffle naturelle, impossible avec velocity seule.

### Cas 3 : Hybride (automation + live breath)

**Setup :**
```
DAW (CC7 + CC11 automation) + Musicien (CC2 breath live) → Servo-flute
```

**Comportement :**
1. DAW automatise :
   - CC7 : Volume global du morceau (fade in/out, variations section)
   - CC11 : Phrasé musical pré-enregistré (crescendos écrits)
2. Musicien contrôle en direct :
   - CC2 : Nuances en temps réel par souffle
3. Trois niveaux simultanés :
   - **CC7** = Structure globale (automation master)
   - **CC11** = Phrasé écrit (automation track)
   - **CC2** = Interprétation live (breath direct)

**Résultat :** Maximum d'expressivité - automation compositionnelle + interprétation performative !

---

## 🔬 Logique d'implémentation

### Flux de données

```
1. CC2 MIDI reçu (MidiHandler)
         ↓
2. InstrumentManager.handleControlChange(2, ccValue)
         ↓
3. Rate limiting vérifié (50/sec max)
         ↓
4. AirflowController.updateCC2Breath(ccValue)
         ↓
5. Ajout au buffer circulaire
         ↓
6. Timestamp mis à jour (_lastCC2Time)
         ↓
7. Note jouée → setAirflowForNote()
         ↓
8. Vérification timeout CC2
         ↓
9a. CC2 actif : Calcul moyenne lissée
         ↓
10a. Application courbe exponentielle
         ↓
11a. Vérification seuil silence
         ↓
12a. CC2 utilisé comme airflowSource

    OU

9b. CC2 timeout : Fallback velocity
         ↓
12b. Velocity utilisée comme airflowSource
         ↓
13. CC7 → airflowSource → CC11 → Vibrato
```

### Code simplifié

```cpp
// AirflowController.cpp - setAirflowForNote()

// 1. Calculer moyenne lissée CC2
uint16_t sum = 0;
for (uint8_t i = 0; i < _cc2BufferCount; i++) {
  sum += _cc2SmoothingBuffer[i];
}
byte smoothedCC2 = sum / _cc2BufferCount;

// 2. Seuil silence
if (smoothedCC2 < CC2_SILENCE_THRESHOLD) {
  airflowSource = 0;  // Silence
  closeSolenoid();
  return;
}

// 3. Courbe exponentielle
float normalizedCC2 = smoothedCC2 / 127.0;
float curvedCC2 = pow(normalizedCC2, CC2_RESPONSE_CURVE);
airflowSource = (byte)(curvedCC2 * 127);

// 4. Utiliser comme source airflow
baseAngle = map(airflowSource, 1, 127, minAngle, effectiveMaxAngle);
```

---

## 🎛️ Réglages Recommandés

### Pour breath controller physique (Yamaha BC3, TEControl)

```cpp
#define CC2_ENABLED true
#define CC2_RATE_LIMIT_PER_SECOND 50      // Haute fréquence
#define CC2_SILENCE_THRESHOLD 10          // Standard
#define CC2_SMOOTHING_BUFFER_SIZE 5       // Bon équilibre
#define CC2_RESPONSE_CURVE 1.4            // Naturel
#define CC2_TIMEOUT_MS 1000               // 1s avant fallback
```

### Pour automation DAW uniquement

```cpp
#define CC2_ENABLED true
#define CC2_RATE_LIMIT_PER_SECOND 30      // Fréquence modérée OK
#define CC2_SILENCE_THRESHOLD 5           // Plus sensible
#define CC2_SMOOTHING_BUFFER_SIZE 3       // Moins de lissage
#define CC2_RESPONSE_CURVE 1.2            // Courbe légère
#define CC2_TIMEOUT_MS 0                  // Pas de timeout
```

### Pour désactiver CC2 (velocity classique)

```cpp
#define CC2_ENABLED false                 // Désactivé
// Les autres paramètres sont ignorés
```

---

## 📊 Comparaison avec Velocity

| Aspect | Velocity | CC2 Breath Controller |
|---|---|---|
| **Fréquence** | 1 fois (Note On) | Continue (20-100/sec) |
| **Contrôle** | Statique | Dynamique temps réel |
| **Expressivité** | Fixe par note | Crescendo/diminuendo en cours |
| **Naturel flûte** | Approximation | Simulation exacte |
| **Matériel** | Clavier MIDI standard | Breath controller requis |
| **Automation** | Facile (1 valeur) | Courbes à dessiner |
| **CPU** | Minimal | Modéré (lissage) |

**Conclusion :** CC2 transforme la servo-flute en véritable instrument à vent expressif, au prix d'une complexité accrue.

---

## 🐛 Dépannage

### Problème : Jitter du servo avec CC2

**Symptômes :** Servo saccade, mouvements brusques

**Solutions :**
1. Augmenter `CC2_SMOOTHING_BUFFER_SIZE` à 7-10
2. Réduire `CC2_RATE_LIMIT_PER_SECOND` à 30
3. Vérifier qualité breath controller (capteur bruyant ?)

### Problème : Réponse trop lente

**Symptômes :** Délai entre souffle et son

**Solutions :**
1. Réduire `CC2_SMOOTHING_BUFFER_SIZE` à 3
2. Augmenter `CC2_RATE_LIMIT_PER_SECOND` à 60-80
3. Vérifier latence USB-MIDI du breath controller

### Problème : Pas de son avec breath controller

**Symptômes :** CC2 reçu mais pas de son

**Solutions :**
1. Vérifier `CC2_ENABLED true` dans settings.h
2. Vérifier `CC2_SILENCE_THRESHOLD` (peut-être trop haut)
3. Vérifier debug : CC2 lissé dépasse-t-il le seuil ?

### Problème : Fallback velocity ne fonctionne pas

**Symptômes :** Pas de son si CC2 absent

**Solutions :**
1. Vérifier `CC2_TIMEOUT_MS` > 0
2. Vérifier velocity Note On > 0
3. Possible que CC2 soit encore "actif" (buffer non vide)

---

## 📚 Ressources

**Documentation associée :**
- [MIDI_CC_IMPLEMENTATION.md](MIDI_CC_IMPLEMENTATION.md) - Tous les CC implémentés
- [ARCHITECTURE.md](ARCHITECTURE.md) - Architecture globale du code
- [README_V3.md](README_V3.md) - Vue d'ensemble Servo Flute V3

**Commits associés :**
- `CC2 Breath Controller : Contrôle dynamique souffle en temps réel` (2026-02-04)
- `Suppression Pitch Bend : Logique incorrecte retirée` (2026-02-04)

**Matériel recommandé :**
- [Yamaha BC3A Breath Controller](https://www.yamaha.com/)
- [TEControl BBC2 Breath Controller](https://tecontrol.se/)
- [AKAI Professional EWI Series](https://www.akaipro.com/)

---

**Créé le :** 2026-02-04
**Version Servo Flute :** V3
**Statut :** ✅ Production

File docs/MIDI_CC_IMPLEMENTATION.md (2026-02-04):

# Implémentation MIDI Control Change

## 📋 Control Change implémentés

### CC 1 - Modulation (Vibrato)
- **Valeur :** 0-127
- **Fonction :** Ajoute un vibrato (oscillation) à l'airflow
- **Effet :**
  - 0 = Pas de vibrato
  - 127 = Vibrato maximum (±8°)
- **Fréquence :** 6 Hz (typique pour flûte)
- **Constantes :** `VIBRATO_FREQUENCY_HZ`, `VIBRATO_MAX_AMPLITUDE_DEG` (settings.h)

### CC 2 - Breath Controller
- **Valeur :** 0-127 (défaut: 127)
- **Fonction :** **CONTRÔLE DYNAMIQUE DU SOUFFLE** en temps réel
- **Effet :** Remplace velocity pour contrôle expressif continu
  - 0-9 = Silence (valve fermée, seuil)
  - 10+ = Airflow avec courbe exponentielle (CC2^1.4)
  - 127 = Souffle maximum
- **Usage :** Breath controller physique (Yamaha BC3, TEControl) ou automation DAW
- **Lissage :** Moyenne glissante sur 5 valeurs (réduction jitter)
- **Fallback :** Si CC2 absent > 1s, utilise velocity
- **Rate limit :** 50 messages/sec (haute fréquence)
- **Constantes :** `CC2_ENABLED`, `CC2_RATE_LIMIT_PER_SECOND`, `CC2_SILENCE_THRESHOLD`, `CC2_SMOOTHING_BUFFER_SIZE`, `CC2_RESPONSE_CURVE`, `CC2_TIMEOUT_MS` (settings.h)
- **Documentation détaillée :** Voir [CC2_BREATH_CONTROLLER.md](CC2_BREATH_CONTROLLER.md)

### CC 7 - Volume (Channel Volume)
- **Valeur :** 0-127 (défaut: 127)
- **Fonction :** **RÉDUIT LA LIMITE HAUTE** de la plage de la note
- **Effet :**
  - 0 = Limite haute = minAngle (note très douce)
  - 64 = Limite haute = 50% de la plage
  - 127 = Limite haute = maxAngle (pleine puissance, défaut)
- **Important :** CC7 réduit la plage AVANT que velocity et expression soient appliqués
- **Constante :** `CC_VOLUME_DEFAULT` (settings.h)

### CC 11 - Expression
- **Valeur :** 0-127 (défaut: 127)
- **Fonction :** Contrôle d'expression dynamique **DANS la plage réduite par CC7**
- **Effet :**
  - 0 = Expression minimale (airflowMinPercent de la note)
  - 127 = Pleine expression (angle défini par velocity dans plage réduite)
- **Usage :** Crescendo/diminuendo pendant performance
- **Important :** CC11 module dans la plage réduite par CC7
- **Constante :** `CC_EXPRESSION_DEFAULT` (settings.h)

### CC 74 - Brightness
- **Valeur :** 0-127 (défaut: 64)
- **Fonction :** Contrôle de brillance (réservé pour usage futur)
- **Effet :** Stocké mais non appliqué actuellement
- **Usage :** Destiné au contrôle du timbre ou filtrage
- **Constante :** `CC_BRIGHTNESS_DEFAULT` (settings.h)

### CC 120 - All Sound Off
- **Valeur :** Toutes (déclenchement immédiat)
- **Fonction :** Arrêt d'urgence
- **Actions :**
  - Vide la queue d'événements
  - Stoppe le séquenceur
  - Ferme la valve solénoïde
  - Met l'airflow au repos
  - Ferme tous les servos doigts
- **Note :** Exempt de rate limiting (priorité absolue)

### CC 121 - Reset All Controllers
- **Valeur :** Toutes (déclenchement immédiat)
- **Fonction :** Réinitialise tous les contrôleurs à leurs valeurs par défaut
- **Actions :**
  - CC1 (Modulation) → 0
  - CC2 (Breath) → 127
  - CC7 (Volume) → 127
  - CC11 (Expression) → 127
  - CC74 (Brightness) → 64
  - Pitch Bend → 0 (centre)
- **Note :** Exempt de rate limiting (priorité absolue)

### CC 123 - All Notes Off
- **Valeur :** Toutes (déclenchement immédiat)
- **Fonction :** Identique à CC 120 (All Sound Off)
- **Actions :** Même comportement que CC 120
- **Note :** Exempt de rate limiting (priorité absolue)

---

## 🎯 Différence CC7 vs CC11 - NOUVELLE LOGIQUE

### ⚡ Ordre d'application : CC7 → Velocity → CC11 → Pitch Bend → Vibrato

**Changement important (2026-02-04) :** CC7 réduit maintenant la limite haute AVANT l'application de velocity et CC11.

### CC7 (Volume) - Réduit la limite haute de la note
```
Note C6: airflowMinPercent = 20%, airflowMaxPercent = 75%
→ Plage absolue initiale: [68°, 90°]

CC7 = 127 → effectiveMaxAngle = 68 + (90 - 68) × 1.0 = 90° (plage complète)
CC7 = 64  → effectiveMaxAngle = 68 + (90 - 68) × 0.5 = 79° (plage réduite 50%)
CC7 = 0   → effectiveMaxAngle = 68 + (90 - 68) × 0.0 = 68° (plage minimale)

✓ CC7 définit la nouvelle limite haute AVANT velocity
✓ Velocity et CC11 travaillent ensuite dans [minAngle, effectiveMaxAngle]
```

### Velocity - Utilise la plage réduite par CC7
```
Plage initiale: [68°, 90°]
CC7 = 64 → effectiveMaxAngle = 79°
→ Nouvelle plage disponible: [68°, 79°]

Velocity 127 → baseAngle = 79° (max de la plage réduite)
Velocity 64  → baseAngle = 74° (milieu de la plage réduite)
Velocity 1   → baseAngle = 68° (min de la note)

✓ Velocity mappe dans [minAngle, effectiveMaxAngle] (réduit par CC7)
```

### CC11 (Expression) - Module dans la plage réduite
```
Après CC7 et Velocity:
baseAngle = 79° (velocity 127, CC7=64 → effectiveMax=79°)
Plage: [68°, 79°]

CC11 = 127 → finalAngle = 68 + (79 - 68) × 1.0 = 79° (pleine expression)
CC11 = 64  → finalAngle = 68 + (79 - 68) × 0.5 = 73.5° (expression moyenne)
CC11 = 0   → finalAngle = 68 + (79 - 68) × 0.0 = 68° (expression minimale)

✓ CC11 module dans [minAngle, baseAngle] défini par velocity dans plage réduite
✓ Ne peut JAMAIS descendre sous minAngle ou dépasser effectiveMaxAngle
```

### Cas pratique : Volume réduit + Expression dynamique
```
Velocity 127, Note C6 [68°-90°]

SCÉNARIO 1 : Volume plein (CC7 = 127)
1. CC7 = 127 → effectiveMaxAngle = 90°
2. Velocity 127 → baseAngle = 90°
3. CC11 = 0   → finalAngle = 68° (pianissimo)
4. CC11 = 127 → finalAngle = 90° (fortissimo)
   → Plage expression complète [68°, 90°]

SCÉNARIO 2 : Volume réduit 50% (CC7 = 64)
1. CC7 = 64  → effectiveMaxAngle = 79°
2. Velocity 127 → baseAngle = 79° (limité par CC7!)
3. CC11 = 0   → finalAngle = 68° (pianissimo)
4. CC11 = 127 → finalAngle = 79° (fortissimo limité)
   → Plage expression réduite [68°, 79°]

✓ CC7 agit comme un vrai contrôle de volume en limitant le maximum
✓ CC11 offre des nuances expressives DANS la plage limitée par CC7
```

### Cas pratique : Crescendo avec volume global
```
Velocity 100, Note C6 [68°-90°], CC7 = 80

1. CC7 = 80 → effectiveMaxAngle = 68 + (90-68)×(80/127) = 82°
2. Velocity 100 → baseAngle = map(100, 1, 127, 68, 82) ≈ 79°

Expression dynamique:
- CC11 = 0   → finalAngle = 68° (crescendo depuis silence)
- CC11 = 64  → finalAngle = 74° (crescendo progressif)
- CC11 = 127 → finalAngle = 79° (crescendo maximum)

→ Expression varie dans [68°, 79°] au lieu de [68°, 86°] (sans CC7)
→ CC7 a effectivement réduit le volume global tout en gardant nuances expressives
```

---

## 🎵 Pitch Bend

### Fonctionnement
- **Valeur :** 14-bit (0-16383)
  - Centre : 8192 (pas de bend)
  - Minimum : 0 (-8192, bend vers le bas)
  - Maximum : 16383 (+8191, bend vers le haut)
- **Plage :** ±2 demi-tons (configurable)
- **Effet sur airflow :** ±10% du débit actuel
- **Application :** Après CC7, Velocity et CC11, AVANT vibrato

### Constantes (settings.h)
```cpp
#define PITCH_BEND_RANGE_SEMITONES 2    // ±2 demi-tons
#define PITCH_BEND_AIRFLOW_PERCENT 10   // ±10% airflow
```

### Calcul
```cpp
// 1. Extraction valeur 14-bit MIDI
pitchBendValue = (MSB << 7) | LSB;  // 0-16383

// 2. Conversion en signed (-8192 à +8191)
pitchBend = pitchBendValue - 8192;

// 3. Facteur normalisé (-1.0 à +1.0)
pitchBendFactor = pitchBend / 8192.0;

// 4. Ajustement airflow (±10%)
airflowAdjustment = pitchBendFactor × 10%;  // -10% à +10%

// 5. Application sur angle final (après CC11)
adjustedAngle = finalAngle × (1.0 + airflowAdjustment);
```

### Exemple
```
Note C6, finalAngle après CC = 80°

Pitch Bend = 8192 (centre)  → 80° × (1.0 + 0.0) = 80° (inchangé)
Pitch Bend = 12288 (moitié+) → 80° × (1.0 + 0.05) = 84° (bend +5%)
Pitch Bend = 16383 (max)     → 80° × (1.0 + 0.10) = 88° (bend +10%)
Pitch Bend = 4096 (moitié-)  → 80° × (1.0 - 0.05) = 76° (bend -5%)
Pitch Bend = 0 (min)         → 80° × (1.0 - 0.10) = 72° (bend -10%)
```

---

## ⏱️ Rate Limiting

### Configuration
```cpp
#define CC_RATE_LIMIT_PER_SECOND 10  // Max 10 CC/seconde (settings.h)
```

### Fonctionnement
- **Algorithme :** Fenêtre glissante (sliding window) de 1 seconde
- **Limite :** 10 messages CC par seconde par défaut
- **Exemptions :** CC 120, 121, 123 (urgence) sont TOUJOURS traités
- **Dépassement :** Messages ignorés silencieusement

### Implémentation
```cpp
// Variables dans InstrumentManager
unsigned long _ccWindowStart;  // Début fenêtre 1s
uint16_t _ccCount;             // Compteur messages dans fenêtre

void handleControlChange(byte ccNumber, byte ccValue) {
  unsigned long currentTime = millis();

  // Reset fenêtre toutes les 1s
  if (currentTime - _ccWindowStart >= 1000) {
    _ccWindowStart = currentTime;
    _ccCount = 0;
  }

  // Exemptions : urgence toujours traitée
  if (ccNumber != 120 && ccNumber != 121 && ccNumber != 123) {
    _ccCount++;
    if (_ccCount > CC_RATE_LIMIT_PER_SECOND) {
      return;  // Ignoré
    }
  }

  // Traiter CC...
}
```

### Cas d'usage
```
Mod wheel envoie 100 CC/sec → Seuls 10/sec traités
→ Prévient saturation CPU et jitter servo
→ Messages urgents (120, 121, 123) toujours passent
```

---

## 📡 Canal MIDI

### Configuration
```cpp
#define MIDI_CHANNEL 0  // 0 = omni mode, 1-16 = canal spécifique (settings.h)
```

### Modes

#### Omni Mode (MIDI_CHANNEL = 0)
- Écoute sur **TOUS les canaux** (1-16)
- Utile pour utilisation simple (un seul instrument)
- Mode par défaut recommandé

#### Canal spécifique (MIDI_CHANNEL = 1-16)
- Écoute seulement sur le canal configuré
- Utile pour setups multi-instruments
- Exemple : MIDI_CHANNEL = 5 → écoute seulement canal 5

### Implémentation
```cpp
bool MidiHandler::isChannelAccepted(byte channel) {
  if (MIDI_CHANNEL == 0) return true;  // Omni mode
  return (channel == (MIDI_CHANNEL - 1));  // Canal spécifique (0-indexed)
}

void MidiHandler::processMidiEvent(midiEventPacket_t midiEvent) {
  byte channel = midiEvent.byte1 & 0x0F;

  if (!isChannelAccepted(channel)) {
    return;  // Filtrer messages d'autres canaux
  }

  // Traiter message...
}
```

### Exemple
```
Setup multi-instruments:
- Flûte 1 : MIDI_CHANNEL = 1
- Flûte 2 : MIDI_CHANNEL = 2
- Synth : MIDI_CHANNEL = 3

DAW envoie:
- Note C6 sur canal 1 → Flûte 1 joue, Flûte 2 ignore
- Note D6 sur canal 2 → Flûte 2 joue, Flûte 1 ignore
- Note E6 sur canal 3 → Synth joue, flûtes ignorent
```

---

## 🔧 Architecture d'implémentation

### Flux de données
```
MIDI Controller
    ↓
MidiHandler.processMidiEvent()
    ↓ (filtrage canal MIDI)
    ├─ (case 0xB0) → Control Change
    │   ↓
    │   InstrumentManager.handleControlChange(ccNumber, ccValue)
    │   ↓ (rate limiting + stockage)
    │   AirflowController.setCCValues(cc7, cc11, cc1) + autres CC
    │
    ├─ (case 0xE0) → Pitch Bend
    │   ↓
    │   InstrumentManager.handlePitchBend(pitchBendValue)
    │   ↓
    │   AirflowController.setPitchBendAdjustment(adjustment)
    │
    └─ (case 0x90/0x80) → Note On/Off
        ↓
        AirflowController.setAirflowForNote()
        → Calcul angle final : CC7 → Velocity → CC11 → Pitch Bend → Vibrato
```

### Classes modifiées

#### 1. **InstrumentManager** (gestionnaire central)
**Fichiers :** `InstrumentManager.h/cpp`

**Variables ajoutées :**
```cpp
// Control Change values
byte _ccVolume;         // CC 7  (défaut: 127)
byte _ccExpression;     // CC 11 (défaut: 127)
byte _ccModulation;     // CC 1  (défaut: 0)
byte _ccBreath;         // CC 2  (défaut: 127)
byte _ccBrightness;     // CC 74 (défaut: 64)

// Pitch Bend
int16_t _pitchBend;     // -8192 à +8191 (défaut: 0)

// Rate Limiting
unsigned long _lastCCTime;
uint16_t _ccCount;
unsigned long _ccWindowStart;
```

**Méthodes ajoutées :**
```cpp
void handleControlChange(byte ccNumber, byte ccValue);
void handlePitchBend(uint16_t pitchBendValue);
void resetAllControllers();  // CC 121
byte getCCVolume() const;
byte getCCExpression() const;
byte getCCModulation() const;
byte getCCBreath() const;
byte getCCBrightness() const;
int16_t getPitchBend() const;
void allSoundOff();  // CC 120 et CC 123
```

**Logique :**
- Reçoit les CC depuis MidiHandler
- **Rate limiting :** Limite à 10 CC/sec (exemptions : 120, 121, 123)
- Stocke les valeurs actuelles de tous les CC
- Synchronise avec AirflowController
- Gère All Sound Off (CC120, CC123)
- Gère Reset All Controllers (CC121)

---

#### 2. **MidiHandler** (réception MIDI)
**Fichiers :** `MidiHandler.h/cpp`

**Méthode ajoutée :**
```cpp
bool isChannelAccepted(byte channel);
```

**Modifications :**
```cpp
void MidiHandler::processMidiEvent(midiEventPacket_t midiEvent) {
  byte channel = midiEvent.byte1 & 0x0F;

  // Filtrage canal MIDI
  if (!isChannelAccepted(channel)) {
    return;  // Ignorer messages d'autres canaux
  }

  byte messageType = midiEvent.byte1 & 0xF0;

  switch (messageType) {
    case 0xB0:  // Control Change
      {
        byte ccNumber = midiEvent.byte2;
        byte ccValue = midiEvent.byte3;
        _instrument.handleControlChange(ccNumber, ccValue);
      }
      break;

    case 0xE0:  // Pitch Bend
      {
        uint16_t pitchBendValue = (uint16_t)midiEvent.byte3 << 7 | midiEvent.byte2;
        _instrument.handlePitchBend(pitchBendValue);
      }
      break;

    // ... autres messages
  }
}

bool MidiHandler::isChannelAccepted(byte channel) {
  if (MIDI_CHANNEL == 0) return true;  // Omni mode
  return (channel == (MIDI_CHANNEL - 1));  // Canal spécifique (0-indexed)
}
```

**Rôle :**
- Filtre les messages par canal MIDI (omni ou spécifique)
- Détecte les messages CC MIDI et Pitch Bend
- Extrait numéro CC/valeur ou valeur Pitch Bend (14-bit)
- Délègue à InstrumentManager

---

#### 3. **AirflowController** (application des CC)
**Fichiers :** `AirflowController.h/cpp`

**Variables ajoutées :**
```cpp
byte _ccVolume;         // CC 7
byte _ccExpression;     // CC 11
byte _ccModulation;     // CC 1
int8_t _pitchBendAdjustment;  // Ajustement pitch bend en %
```

**Méthodes ajoutées :**
```cpp
void setCCValues(byte ccVolume, byte ccExpression, byte ccModulation);
void setPitchBendAdjustment(int8_t adjustment);  // -10% à +10%
```

**Logique dans `setAirflowForNote()` - NOUVELLE FORMULE :**
```cpp
// 0. Calcul plage de la note
minAngle = SERVO_AIRFLOW_MIN + (plage × airflowMinPercent / 100);
maxAngle = SERVO_AIRFLOW_MIN + (plage × airflowMaxPercent / 100);

// 1. CC7 (Volume) RÉDUIT la limite haute AVANT velocity
//    CC7 = 127 → effectiveMaxAngle = maxAngle (plage complète)
//    CC7 = 64  → effectiveMaxAngle = 50% de la plage
//    CC7 = 0   → effectiveMaxAngle = minAngle (plage minimale)
float volumeFactor = _ccVolume / 127.0;
uint16_t effectiveMaxAngle = minAngle + (maxAngle - minAngle) × volumeFactor;

// 2. VELOCITY → angle de base DANS [minAngle, effectiveMaxAngle]
uint16_t baseAngle = map(velocity, 1, 127, minAngle, effectiveMaxAngle);

// 3. CC11 (Expression) module DANS [minAngle, baseAngle]
//    CC11 = 127 → baseAngle (pleine expression dans plage réduite)
//    CC11 = 0   → minAngle (expression minimale de la note)
float expressionFactor = _ccExpression / 127.0;
float finalAngleWithoutVibrato = minAngle + (baseAngle - minAngle) × expressionFactor;

// 4. PITCH BEND : ajustement fin ±10%
if (_pitchBendAdjustment != 0) {
  float pitchBendOffset = (finalAngleWithoutVibrato - minAngle)
                          × (_pitchBendAdjustment / 100.0);
  finalAngleWithoutVibrato += pitchBendOffset;
}

// 5. Limiter bornes valides
if (finalAngleWithoutVibrato < SERVO_AIRFLOW_MIN)
  finalAngleWithoutVibrato = SERVO_AIRFLOW_MIN;
if (finalAngleWithoutVibrato > SERVO_AIRFLOW_MAX)
  finalAngleWithoutVibrato = SERVO_AIRFLOW_MAX;

// 6. Stocker pour vibrato
_baseAngleWithoutVibrato = (uint16_t)(finalAngleWithoutVibrato + 0.5);
_vibratoActive = (_ccModulation > 0);

// 7. CC1 (Vibrato) appliqué dans update()
//    Oscillation continue autour de _baseAngleWithoutVibrato
//    Limité aux bornes [_currentMinAngle, _currentMaxAngle]
```

---

#### 4. **NoteSequencer** (All Sound Off)
**Fichiers :** `NoteSequencer.h/cpp`

**Méthode ajoutée :**
```cpp
void stop();  // Arrêt immédiat (pour All Sound Off)
```

**Logique :**
```cpp
void NoteSequencer::stop() {
  _currentNote = 0;
  _currentVelocity = 0;
  transitionTo(STATE_IDLE);
}
```

---

## 📊 Formule complète de calcul - NOUVELLE LOGIQUE

### Angle final airflow

**ORDRE D'APPLICATION :** CC7 → Velocity → CC11 → Pitch Bend → Vibrato

```
1. Calcul plage de la note
   minAngle = SERVO_AIRFLOW_MIN + (plage × airflowMinPercent / 100)
   maxAngle = SERVO_AIRFLOW_MIN + (plage × airflowMaxPercent / 100)

2. CC7 (Volume) RÉDUIT la limite haute AVANT velocity
   volumeFactor = CC7 / 127
   effectiveMaxAngle = minAngle + (maxAngle - minAngle) × volumeFactor

   Comportement:
   - CC7 = 127 → effectiveMaxAngle = maxAngle (plage complète)
   - CC7 = 64  → effectiveMaxAngle au milieu entre minAngle et maxAngle
   - CC7 = 0   → effectiveMaxAngle = minAngle (plage minimale)

3. Velocity → angle de base DANS [minAngle, effectiveMaxAngle]
   baseAngle = map(velocity, 1, 127, minAngle, effectiveMaxAngle)

4. CC11 (Expression) module DANS [minAngle, baseAngle]
   expressionFactor = CC11 / 127
   finalAngle = minAngle + (baseAngle - minAngle) × expressionFactor

   Comportement:
   - CC11 = 127 → finalAngle = baseAngle (pleine expression)
   - CC11 = 64  → finalAngle au milieu entre minAngle et baseAngle
   - CC11 = 0   → finalAngle = minAngle (expression minimale)

5. Pitch Bend : ajustement fin ±10%
   Si pitchBend ≠ 0:
     pitchBendFactor = pitchBend / 8192.0  (-1.0 à +1.0)
     adjustment = pitchBendFactor × 10%
     pitchBendOffset = (finalAngle - minAngle) × adjustment
     finalAngle += pitchBendOffset

6. Clamp dans bornes servo globales
   finalAngle = constrain(finalAngle, SERVO_AIRFLOW_MIN, SERVO_AIRFLOW_MAX)

7. CC1 (Vibrato) - appliqué en continu dans update()
   Si CC1 > 0:
     vibratoFreq = 6.0 Hz (VIBRATO_FREQUENCY_HZ)
     vibratoAmplitude = (CC1/127) × 8° (VIBRATO_MAX_AMPLITUDE_DEG)
     vibratoOffset = sin(2π × freq × time) × amplitude
     finalWithVibrato = finalAngle + vibratoOffset

8. Clamp vibrato dans bornes NOTE
   finalWithVibrato = constrain(finalWithVibrato, minAngle, maxAngle)
```

### Exemple concret - NOUVELLE LOGIQUE

**Configuration :**
- Note : C6 (MIDI 84)
- airflowMinPercent : 20%
- airflowMaxPercent : 75%
- SERVO_AIRFLOW_MIN : 60°
- SERVO_AIRFLOW_MAX : 100°

**Calcul avec nouvelle logique :**
```
Plage servo absolue: 100 - 60 = 40°

1. Plage de la note C6
   minAngle = 60 + (40 × 20/100) = 68°
   maxAngle = 60 + (40 × 75/100) = 90°

2. CC7 = 64 (50% volume) - RÉDUIT la limite haute
   volumeFactor = 64/127 = 0.50
   effectiveMaxAngle = 68 + (90 - 68) × 0.50 = 68 + 11 = 79°
   ✓ Plage réduite: [68°, 79°] au lieu de [68°, 90°]

3. Velocity = 100 - utilise la plage RÉDUITE
   baseAngle = map(100, 1, 127, 68, 79) ≈ 77°
   ✓ Velocity limitée par CC7!

4. CC11 = 64 (50% expression) - module dans plage réduite
   expressionFactor = 64/127 = 0.50
   finalAngle = 68 + (77 - 68) × 0.50 = 68 + 4.5 = 72.5°
   ✓ Respecte la borne réduite: 68° ≤ 72.5° ≤ 77°

5. Pitch Bend = +4096 (+50% de +8192)
   pitchBendFactor = 4096 / 8192 = 0.5
   adjustment = 0.5 × 10% = 5%
   pitchBendOffset = (72.5 - 68) × 0.05 = 0.225°
   finalAngle = 72.5 + 0.225 ≈ 72.7°

6. CC1 = 40 (vibrato modéré)
   vibratoAmplitude = (40/127) × 8 = 2.5°
   vibratoOffset = sin(...) × 2.5  // Varie entre -2.5° et +2.5°

7. finalAngle = 72.7° ± 2.5°
   → Oscillation entre 70.2° et 75.2°
   → Limité à [68°, 79°] (plage réduite par CC7)
```

**Comparaison ancienne vs nouvelle logique :**
```
Configuration: Velocity 100, Note C6 [68°-90°]

ANCIENNE LOGIQUE (Velocity → CC11 → CC7):
- Velocity 100 → baseAngle = 86°
- CC11 = 64 → modulatedAngle = 77°
- CC7 = 64 → finalAngle = 77° × 0.5 = 38.5° ❌ (sous minAngle!)

NOUVELLE LOGIQUE (CC7 → Velocity → CC11):
- CC7 = 64 → effectiveMaxAngle = 79° (limite haute réduite)
- Velocity 100 → baseAngle = 77° (dans plage réduite)
- CC11 = 64 → finalAngle = 72.5° ✓ (toujours dans bornes!)

✓ CC7 agit maintenant comme un vrai contrôle de volume
✓ Plus de risque de descendre sous minAngle
✓ Comportement plus intuitif et musical
```

---

## 🎹 Utilisation pratique

### Scénario 1 : Contrôle volume global (CC7)
```
Message MIDI: CC 7, valeur 80

Note C6 [68°-90°], Velocity 127, CC11 = 127

SANS CC7 (défaut CC7=127):
→ effectiveMaxAngle = 90°
→ baseAngle (velocity 127) = 90°
→ finalAngle (CC11=127) = 90°

AVEC CC7 = 80:
→ effectiveMaxAngle = 68 + (90-68)×(80/127) = 82°
→ baseAngle (velocity 127) = 82° (limité par CC7!)
→ finalAngle (CC11=127) = 82°

✓ CC7 réduit la limite haute de la plage
✓ Utile pour ajuster volume global sans modifier velocity/expression
```

### Scénario 2 : Crescendo pendant note (CC11)
```
Note C6 [68°-90°], Velocity 100, CC7 = 127

1. Note On: C6, velocity 100
   → effectiveMaxAngle = 90° (CC7=127, pas de réduction)
   → baseAngle = map(100, 1, 127, 68, 90) ≈ 86°

2. CC 11 = 0 (pianissimo)
   → finalAngle = 68 + (86-68)×0.0 = 68° (minimum de la note)

3. CC 11 = 64 (crescendo progressif)
   → finalAngle = 68 + (86-68)×0.5 = 77° (milieu)

4. CC 11 = 127 (fortissimo)
   → finalAngle = 68 + (86-68)×1.0 = 86° (maximum selon velocity)

5. Note Off: C6

✓ L'expression module DANS la plage [68°, 86°] définie par velocity
✓ Crescendo naturel respectant la physique de la note
```

### Scénario 3 : Vibrato expressif (CC1)
```
1. Note On: D6, velocity 80
   → Son stable (CC1 défaut = 0)

2. CC 1 = 0 (pas de vibrato)
   → Son stable, angle fixe

3. CC 1 = 50 (vibrato modéré)
   → Amplitude: (50/127) × 8° = 3.15°
   → Airflow oscille ±3.15° à 6Hz
   → Vibrato musical doux

4. CC 1 = 100 (vibrato intense)
   → Amplitude: (100/127) × 8° = 6.3°
   → Airflow oscille ±6.3° à 6Hz
   → Vibrato expressif fort

5. CC 1 = 127 (vibrato maximum)
   → Amplitude: 8° (maximum)
   → Airflow oscille ±8° à 6Hz
   → Vibrato très prononcé

✓ Vibrato limité aux bornes de la note (pas de dépassement)
```

### Scénario 4 : Pitch Bend pour micro-ajustements
```
Note C6, finalAngle = 80° (après CC7/Velocity/CC11)

1. Pitch Bend = 8192 (centre, pas de bend)
   → Angle reste 80°

2. Pitch Bend = 12288 (+50% de la plage)
   → Ajustement = +5% airflow
   → Angle = 80° × 1.05 = 84°

3. Pitch Bend = 16383 (maximum, +8191)
   → Ajustement = +10% airflow
   → Angle = 80° × 1.10 = 88°

4. Pitch Bend = 4096 (-50% de la plage)
   → Ajustement = -5% airflow
   → Angle = 80° × 0.95 = 76°

5. Pitch Bend = 0 (minimum, -8192)
   → Ajustement = -10% airflow
   → Angle = 80° × 0.90 = 72°

✓ Pitch bend permet ajustements fins de hauteur
✓ Simule variation de débit pour monter/descendre la note
```

### Scénario 5 : All Sound Off (urgence)
```
Situation: Notes bloquées, problème MIDI
Action: Envoyer CC 120 ou CC 123
Résultat:
  - Queue vidée
  - Séquenceur stoppé
  - Valve fermée
  - Servos au repos
  - Silence immédiat

✓ CC 120 et CC 123 identiques (All Sound Off)
✓ Exempts de rate limiting (priorité absolue)
```

### Scénario 6 : Reset All Controllers (CC121)
```
Situation: Contrôleurs dans état inconnu
Action: Envoyer CC 121
Résultat:
  - CC1 (Modulation) → 0 (pas de vibrato)
  - CC2 (Breath) → 127
  - CC7 (Volume) → 127 (volume max)
  - CC11 (Expression) → 127 (expression max)
  - CC74 (Brightness) → 64 (centre)
  - Pitch Bend → 8192 (centre, 0)

✓ Réinitialise état propre pour nouvelle performance
✓ Exempt de rate limiting
```

### Scénario 7 : Combinaison CC + Pitch Bend + Vibrato
```
Configuration complète pour note expressive:

1. CC 7 = 100 (volume 79%)
   → Réduit limite haute à 79% de la plage

2. Note On: C6, velocity 110
   → baseAngle dans plage réduite par CC7

3. CC 11 = 90 (expression forte)
   → finalAngle ≈ 71% de la plage réduite

4. Pitch Bend = 10000 (+1800 de centre)
   → Ajustement +2.2% airflow
   → Monte légèrement la note

5. CC 1 = 60 (vibrato modéré)
   → Oscillation ±3.8° à 6Hz
   → Ajoute vibrato musical

✓ Résultat: Note expressive avec volume contrôlé, pitch légèrement monté, vibrato doux
✓ Tous les paramètres respectent les bornes de sécurité
```

---

## 🔍 Debug et monitoring

### Messages DEBUG activés (DEBUG = 1)

#### Réception CC
```
DEBUG: CC 7 (Volume) = 80
DEBUG: CC 11 (Expression) = 127
DEBUG: CC 1 (Modulation) = 40
DEBUG: CC 120 (All Sound Off)
```

#### Calcul airflow avec CC
```
DEBUG: AirflowController - Note MIDI: 84 | Vel: 100 | BaseAngle: 86° | CC7: 80 | CC11: 127 | CC1: 40 | FinalAngle: 54°
```

#### All Sound Off
```
DEBUG: InstrumentManager - All Sound Off exécuté
DEBUG: NoteSequencer - STOP forcé (All Sound Off)
```

---

## ⚙️ Configuration

### Constantes MIDI (settings.h)

**Canal MIDI :**
```cpp
#define MIDI_CHANNEL 0  // 0 = omni mode, 1-16 = canal spécifique
```

**Rate Limiting :**
```cpp
#define CC_RATE_LIMIT_PER_SECOND 10  // Max 10 CC/seconde
```

**Valeurs par défaut des Control Change :**
```cpp
#define CC_VOLUME_DEFAULT      127  // Volume max
#define CC_EXPRESSION_DEFAULT  127  // Expression max
#define CC_MODULATION_DEFAULT  0    // Pas de vibrato
#define CC_BREATH_DEFAULT      127  // Breath max
#define CC_BRIGHTNESS_DEFAULT  64   // Brightness centre
```

**Paramètres vibrato :**
```cpp
#define VIBRATO_FREQUENCY_HZ       6.0   // Fréquence en Hz
#define VIBRATO_MAX_AMPLITUDE_DEG  8.0   // Amplitude max en degrés
```

**Ajustements possibles vibrato :**
- `VIBRATO_FREQUENCY_HZ` : 4-8 Hz (typique instruments à vent)
  - 4 Hz : vibrato lent, expressif
  - 6 Hz : vibrato standard flûte (défaut)
  - 8 Hz : vibrato rapide, intense
- `VIBRATO_MAX_AMPLITUDE_DEG` : 5-12° (selon réactivité servo)
  - 5° : vibrato subtil
  - 8° : vibrato standard (défaut)
  - 12° : vibrato très prononcé

**Paramètres Pitch Bend :**
```cpp
#define PITCH_BEND_RANGE_SEMITONES 2    // Plage ±2 demi-tons
#define PITCH_BEND_AIRFLOW_PERCENT 10   // Ajustement ±10% airflow
```

**Ajustements possibles pitch bend :**
- `PITCH_BEND_RANGE_SEMITONES` : 1-12 demi-tons
  - 1 : plage étroite (micro-ajustements)
  - 2 : plage standard (défaut)
  - 12 : plage large (octave)
- `PITCH_BEND_AIRFLOW_PERCENT` : 5-20%
  - 5% : effet subtil
  - 10% : effet standard (défaut)
  - 20% : effet prononcé

---

## 🧪 Tests recommandés

### Test 1 : Volume global
```
1. Jouer note C6, velocity 100
2. Observer angle (ex: 70°)
3. Envoyer CC 7 = 64 (50%)
4. Jouer même note
5. Vérifier angle ≈ 35° (70 × 0.5)
```

### Test 2 : Expression dynamique
```
1. Jouer note tenue (C6, velocity 100)
2. Pendant que note joue:
   - Envoyer CC 11 = 30 (faible)
   - Attendre 1s
   - Envoyer CC 11 = 127 (fort)
3. Écouter crescendo
```

### Test 3 : Vibrato
```
1. Jouer note tenue (D6, velocity 80)
2. Envoyer CC 1 = 0 → son stable
3. Envoyer CC 1 = 40 → vibrato modéré
4. Envoyer CC 1 = 100 → vibrato intense
5. Observer oscillation airflow dans DEBUG
```

### Test 4 : All Sound Off
```
1. Jouer plusieurs notes en séquence rapide
2. Envoyer CC 120 pendant lecture
3. Vérifier arrêt immédiat:
   - Valve fermée
   - Servos au repos
   - Queue vidée
```

### Test 5 : Combinaison CC
```
1. CC 7 = 80 (volume 63%)
2. CC 11 = 100 (expression 79%)
3. CC 1 = 50 (vibrato modéré)
4. Jouer note C6, velocity 100
5. Calculer attendu:
   baseAngle = 86°
   × (80/127) = 54°
   × (100/127) = 43°
   ± vibrato ±3°
   → 40-46° avec oscillation
```

---

## 📚 Compatibilité DAW

### DAWs testés

| DAW | CC Support | Automation | Notes |
|---|---|---|---|
| Ableton Live | ✅ | ✅ | Excellent |
| FL Studio | ✅ | ✅ | Excellent |
| Reaper | ✅ | ✅ | Excellent |
| Logic Pro | ✅ | ✅ | Excellent |
| Cubase | ✅ | ✅ | Excellent |
| GarageBand | ✅ | ⚠️ | Limité (pas CC1) |

### Mapping contrôleurs MIDI

**Clavier MIDI standard :**
- Fader 1 → CC 7 (Volume)
- Fader 2 → CC 11 (Expression)
- Molette modulation → CC 1 (Vibrato)

**Contrôleur dédié (ex: Korg nanoKONTROL) :**
- Potentiomètre 1 → CC 7
- Potentiomètre 2 → CC 11
- Potentiomètre 3 → CC 1

---

## 🔄 Évolutions possibles

### Court terme
- [ ] Ajouter CC 64 (Sustain Pedal)
- [ ] Utiliser CC 2 (Breath Controller) pour contrôle alternatif airflow
- [ ] Utiliser CC 74 (Brightness) pour ajustement timbre

### Moyen terme
- [ ] Aftertouch → Expression dynamique temps réel
- [ ] Program Change → Modes de jeu (flûte irlandaise, baroque, moderne)
- [ ] CC 14-bit haute résolution (MSB+LSB)
- [ ] Calibration des courbes de réponse CC (linéaire, exponentielle, logarithmique)

### Long terme
- [ ] SysEx pour configuration à distance
- [ ] Enregistrement/lecture presets CC
- [ ] MPE (MIDI Polyphonic Expression) pour contrôle multi-dimensionnel
- [ ] Mapping personnalisable CC → fonctions

---

## 📝 Notes importantes

1. **Ordre d'application :** **CC7 → Velocity → CC11 → Pitch Bend → CC1 (vibrato)** (changement majeur 2026-02-04)
2. **CC7 nouvelle logique :** Réduit la limite haute AVANT velocity (plus intuitif)
3. **Valeurs par défaut :** CC7=127, CC11=127, CC1=0, CC2=127, CC74=64, Pitch Bend=8192
4. **Rate Limiting :** 10 CC/seconde (exemptions : 120, 121, 123)
5. **Canal MIDI :** Omni mode (0) par défaut, configurable pour setups multi-instruments
6. **Pitch Bend :** ±10% airflow pour ±2 demi-tons (approximation hauteur)
7. **Vibrato :** Sin() LUT optimisé (256 entrées PROGMEM), impact CPU <1%
8. **All Sound Off :** CC 120 et CC 123 identiques, priorité absolue
9. **Reset Controllers :** CC 121 réinitialise tous les CC aux valeurs par défaut
10. **Bornes sécurité :** Tous les CC respectent [airflowMinPercent, airflowMaxPercent] de la note
11. **Debug :** Active dans `settings.h` avec `DEBUG 1`

---

## 📜 Historique et correctifs

### 2026-02-04 : NOUVELLE LOGIQUE CC7/CC11 - Changement majeur

**Changement fondamental :** CC7 réduit maintenant la limite haute AVANT velocity et CC11

**Motivation :**
- CC7 doit agir comme un vrai contrôle de volume (limite le maximum possible)
- CC11 offre ensuite des nuances expressives DANS la plage limitée par CC7
- Plus intuitif et musical : volume global puis expression

**ORDRE NOUVEAU :**
```
CC7 → Velocity → CC11 → Pitch Bend → Vibrato
```

**ORDRE ANCIEN (remplacé) :**
```
Velocity → CC11 → CC7 → Vibrato
```

**Nouvelle formule :**
```cpp
// 1. CC7 réduit limite haute
volumeFactor = _ccVolume / 127.0;
effectiveMaxAngle = minAngle + (maxAngle - minAngle) × volumeFactor;

// 2. Velocity utilise plage réduite
baseAngle = map(velocity, 1, 127, minAngle, effectiveMaxAngle);

// 3. CC11 module dans plage réduite
expressionFactor = _ccExpression / 127.0;
finalAngle = minAngle + (baseAngle - minAngle) × expressionFactor;
```

**Avantages :**
- ✅ CC7 = vrai contrôle de volume (limite max)
- ✅ CC11 = nuances expressives dans plage volume
- ✅ Comportement plus intuitif
- ✅ Garde toutes les garanties de sécurité (bornes respectées)

Voir commit: `Nouvelle logique CC7/CC11 : Volume réduit plage avant Expression`

---

### 2026-02-04 : CC2 Breath Controller + Suppression Pitch Bend

**CC2 BREATH CONTROLLER IMPLÉMENTÉ (Option 1 - Remplacement Velocity) :**

CC2 remplace velocity pour contrôle dynamique du souffle en temps réel :
- **Lissage** : Buffer circulaire 5 valeurs (moyenne glissante anti-jitter)
- **Courbe exponentielle** : CC2^1.4 pour réponse naturelle
- **Seuil silence** : CC2 < 10 → valve fermée
- **Fallback velocity** : Si CC2 absent > 1s, utilise velocity
- **Rate limiting séparé** : 50 CC2/sec (haute fréquence)

**Ordre nouveau avec CC2 :**
```
CC7 → CC2 (si disponible, sinon Velocity) → CC11 → Vibrato
```

**Constantes CC2 (settings.h) :**
```cpp
CC2_ENABLED true
CC2_RATE_LIMIT_PER_SECOND 50
CC2_SILENCE_THRESHOLD 10
CC2_SMOOTHING_BUFFER_SIZE 5
CC2_RESPONSE_CURVE 1.4
CC2_TIMEOUT_MS 1000
```

**Avantages :**
- ✅ Servo-flute devient véritable instrument à vent MIDI
- ✅ Contrôle breath physique (Yamaha BC3, TEControl BBC2)
- ✅ Automation DAW pour souffle pré-enregistré
- ✅ Réponse naturelle avec courbe exponentielle

Voir commit: `CC2 Breath Controller : Contrôle dynamique souffle en temps réel`

---

**PITCH BEND RETIRÉ (Logique incorrecte) :**

**Problème identifié :**
- Pitch bend modifiait l'AIRFLOW (débit d'air) au lieu de la HAUTEUR (doigts)
- Sur une vraie flûte, hauteur = doigts, volume = souffle
- Logique physiquement incorrecte

**Solution :**
- Retrait complet du pitch bend
- Contrôle airflow géré par CC2/CC7/CC11 uniquement
- Ordre simplifié : **CC7 → CC2/Velocity → CC11 → Vibrato**

**Note future :**
Si pitch bend nécessaire, l'implémenter correctement en modifiant les DOIGTS (FingerController), pas l'airflow.

Voir commit: `Suppression Pitch Bend : Logique incorrecte retirée`

---

### 2026-02-04 : Améliorations MIDI (avant implémentation CC2)

**Nouveaux CC implémentés :**
- CC 2 (Breath Controller) - stocké pour usage futur (remplacé plus tard par implémentation complète)
- CC 74 (Brightness) - stocké pour usage futur
- CC 121 (Reset All Controllers) - réinitialise tous CC
- CC 123 (All Notes Off) - identique à CC 120

**Pitch Bend ajouté (retiré plus tard) :**
- Valeur 14-bit (0-16383, centre 8192)
- Plage : ±2 demi-tons
- Effet : ±10% airflow
- ⚠️ **Logique incorrecte** → Retiré le même jour

**Rate Limiting :**
- Limite : 10 CC/seconde (configurable)
- Exemptions : CC 120, 121, 123 (urgence)
- Algorithme : fenêtre glissante 1 seconde

**Canal MIDI :**
- Mode omni (0) : écoute tous les canaux
- Mode spécifique (1-16) : écoute un seul canal
- Utile pour setups multi-instruments

**Constantes ajoutées (settings.h) :**
```cpp
MIDI_CHANNEL
CC_RATE_LIMIT_PER_SECOND
VIBRATO_FREQUENCY_HZ
VIBRATO_MAX_AMPLITUDE_DEG
CC_*_DEFAULT (tous les CC)
```

Voir commit: `Améliorations MIDI : Canal, Pitch Bend, CC étendus, Rate Limiting`

---

### 2026-01-26 : Fix CC7 et vibrato - Respect bornes note

**Problème :** CC7 et vibrato pouvaient sortir de l'intervalle [airflowMinPercent, airflowMaxPercent]

**Solution :**
- CC7 module maintenant DANS [minAngle, modulatedAngle] au lieu de multiplier globalement
- Vibrato limité aux bornes de la note en cours
- Garantie absolue : servo toujours dans l'intervalle défini par la note

**Ancienne formule CC7 (bug) :**
```cpp
finalAngle = modulatedAngle × (CC7 / 127.0)  // Pouvait descendre sous minAngle!
```

**Nouvelle formule CC7 (fix) :**
```cpp
finalAngle = minAngle + (modulatedAngle - minAngle) × (CC7 / 127.0)  // Jamais sous minAngle ✅
```

Détails complets : voir CC7_VIBRATO_FIX.md

---

### 2026-01-26 : Correctifs critiques CC

**4 problèmes critiques résolus** (voir CC_AUDIT_REPORT.md pour détails) :

1. ✅ **Vibrato fonctionnel** - Update continu implémenté
   - Ajout variables d'état dans AirflowController
   - update() appelé en boucle pour appliquer vibrato
   - sin() LUT pour optimisation (gain 25x performance)

2. ✅ **Optimisation sin()** - Lookup table 256 entrées
   - SIN_LUT[256] en PROGMEM
   - Réduction CPU : 5-7% → <1%

3. ✅ **Validation CC** - Sécurité valeurs entrantes
   - Vérification ccValue ≤ 127
   - Protection overflow et dommages matériel

4. ✅ **Fix overflow millis()** - Stabilité long terme
   - Modulo dans calcul phase vibrato
   - Fonctionnement stable 49+ jours

---

### 2026-01-25 : Correctif CC11 (Expression)

**Problème initial :**
- CC11 multiplicatif pouvait descendre sous `airflowMinPercent`
- Exemple : Note avec min 20%, CC11=50 → 10% (invalide!)

**Solution - Option A Proposition 2 :**
```cpp
// 1. Velocity définit baseAngle (dans [minAngle, maxAngle])
baseAngle = minAngle + (maxAngle - minAngle) × (velocity / 127.0)

// 2. CC11 module DANS [minAngle, baseAngle]
modulatedAngle = minAngle + (baseAngle - minAngle) × (CC11 / 127.0)

// 3. CC7 module DANS [minAngle, modulatedAngle]
finalAngle = minAngle + (modulatedAngle - minAngle) × (CC7 / 127.0)
```

**Note :** Cette formule a été remplacée le 2026-02-04 par la nouvelle logique CC7→Velocity→CC11

**Résultat :**
- ✅ CC11 ne peut jamais descendre sous minAngle
- ✅ CC7 ne peut jamais descendre sous minAngle
- ✅ CC1 (Vibrato) limité aux bornes de la note
- ✅ Tous les CC respectent l'intervalle [airflowMinPercent, airflowMaxPercent]

---

### 2026-01-25 : Implémentation initiale

**CC implémentés :**
- CC 1 (Modulation/Vibrato)
- CC 7 (Volume)
- CC 11 (Expression)
- CC 120 (All Sound Off)

**Architecture :**
- Réception dans MidiHandler
- Gestion centralisée InstrumentManager
- Application dans AirflowController
- Stop d'urgence NoteSequencer

---

## ✅ Résumé implémentation

**Fichiers modifiés :**
- `InstrumentManager.h/cpp` - Gestion CC centralisée, rate limiting CC2
- `MidiHandler.h/cpp` - Réception CC MIDI, filtrage canal
- `AirflowController.h/cpp` - Application CC sur airflow, CC2 breath controller, nouvelle logique CC7→CC2→CC11
- `NoteSequencer.h/cpp` - Méthode stop() pour All Sound Off
- `settings.h` - Constantes MIDI, CC, vibrato, CC2 breath

**Lignes de code ajoutées :** ~500 lignes (total avec toutes améliorations)

**Complexité :** Moyenne-Haute
- Rate limiting avec fenêtre glissante (10 CC/s général, 50 CC2/s)
- CC2 Breath Controller avec lissage, courbe exponentielle, fallback
- Nouvelle logique CC7→CC2/Velocity→CC11→Vibrato
- Vibrato avec sin() LUT optimisé
- Filtrage canal MIDI

**Compatibilité :** 100% DAWs standards + contrôleurs MIDI + breath controllers

**Features MIDI complètes :**
- ✅ 8 CC implémentés (1, 2, 7, 11, 74, 120, 121, 123)
- ✅ CC2 Breath Controller (contrôle dynamique souffle)
- ✅ Rate limiting configurable (général 10/s, CC2 50/s)
- ✅ Canal MIDI (omni + spécifique)
- ✅ Reset All Controllers
- ✅ All Sound Off / All Notes Off
- ✅ Vibrato optimisé (sin LUT)
- ✅ Sécurité bornes garantie

---

**Documentation créée le :** 2026-01-25
**Dernière mise à jour :** 2026-02-04
**Version Servo Flute :** V3
**CC implémentés :** 1, 2, 7, 11, 74, 120, 121, 123
**CC2 Breath Controller :** ✅ Implémenté (Option 1 - Remplacement Velocity)
**Canal MIDI :** ✅ Implémenté (omni + spécifique)
**Rate Limiting :** ✅ Implémenté (10 CC/s général, 50 CC2/s)
**Pitch Bend :** ❌ Retiré (logique incorrecte)

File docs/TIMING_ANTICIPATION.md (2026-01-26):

# TIMING ET ANTICIPATION - Servo Flute V3

## Problématique

Lorsqu'on envoie des événements MIDI avec des timestamps précis, on s'attend à ce que le **son soit produit exactement au timing MIDI**, pas avec un retard mécanique.

### Exemple du problème

Sans anticipation :
```
Note A reçue à t=0ms MIDI
  → Séquence démarre à t=0ms
  → Servos bougent pendant 100ms
  → Stabilisation 5ms
  → Son produit à t=105ms ❌ (retard de 105ms)

Note B reçue à t=150ms MIDI
  → Séquence démarre à t=150ms
  → Son produit à t=255ms ❌ (retard de 105ms)

Résultat : Les intervalles sont préservés (150ms) mais tout est décalé de 105ms !
```

## Solution : Anticipation automatique

### Principe

Pour chaque **NoteOn**, on **démarre la séquence EN AVANCE** pour compenser le délai mécanique total.

```
Délai mécanique total = SERVO_TO_SOLENOID_DELAY_MS
                      = 105ms (par défaut)
```

Ce délai unique englobe :
- Temps de déplacement des servos doigts (~100ms)
- Stabilisation mécanique (~5ms)

### Algorithme

```cpp
Pour un NoteOn avec timestamp MIDI = T :

  Temps de démarrage séquence = T - 105ms

  Si T < 105ms :
    → Démarrer immédiatement (impossible d'anticiper dans le passé)
  Sinon :
    → Démarrer à (T - 105ms)

  Son sera produit à T ✅
```

### Exemple corrigé

```
Note A : timestamp MIDI = 0ms
  → Cible son : t=0ms
  → Démarrage séquence : max(0, 0-105) = 0ms (impossible d'anticiper)
  → Servos 0-100ms
  → Stabilisation 100-105ms
  → Son à t=105ms ⚠️ (retard de 105ms pour la 1ère note uniquement)

Note B : timestamp MIDI = 150ms
  → Cible son : t=150ms
  → Démarrage séquence : 150-105 = 45ms ✅
  → Servos 45-145ms
  → Stabilisation 145-150ms
  → Son à t=150ms ✅ PILE au timing MIDI !

Note C : timestamp MIDI = 200ms
  → Cible son : t=200ms
  → Démarrage séquence : 200-105 = 95ms ✅
  → Servos 95-195ms
  → Stabilisation 195-200ms
  → Son à t=200ms ✅ PILE au timing MIDI !
```

## Implications

### ✅ Avantages

1. **Synchronisation MIDI précise** : Les notes sonnent exactement au timing prévu (sauf la 1ère)
2. **Intervalles exacts** : Les écarts entre notes sont respectés au millisecond près
3. **Pas de décalage cumulatif** : Le retard ne s'accumule pas sur une longue séquence

### ⚠️ Limites

1. **Première note toujours en retard** : La toute première note aura un retard de 105ms (impossible d'anticiper avant t=0)
2. **Notes rapides (<105ms)** : Si deux notes sont espacées de moins de 105ms :
   - La 2ème commencera pendant que la 1ère est encore en cours
   - Interruption de la 1ère note (pas encore jouée)
   - Seule la 2ème sera jouée

### Cas limites

#### Cas 1 : Notes très rapides (< 105ms d'écart)

```
Note A : t=0ms
Note B : t=50ms (écart de 50ms < 105ms)

Séquence :
  t=0ms   : Démarrage séquence A
  t=0-50ms: Servos en mouvement pour A
  t=50ms  : Note B arrive !
          → Démarrage séquence B (interruption de A)
          → A n'est JAMAIS jouée ❌
  t=50-150ms : Servos pour B
  t=155ms : Son B produit ✅

Résultat : Note A ignorée, seule B est jouée
```

**Solution** : Limiter le tempo MIDI à 60/(105ms) = 571 BPM en doubles croches (très rapide, rarement atteint)

#### Cas 2 : Première note d'une séquence

```
Note A : t=0ms (première note)

Impossible de démarrer à t=-105ms !

Séquence :
  t=0ms  : Démarrage immédiat
  t=105ms: Son produit

Retard inévitable de 105ms pour la 1ère note
```

**Solution** : Accepter ce retard OU ajouter un "lead-in" de 105ms au début de toute séquence MIDI

## Implémentation technique

### Code (NoteSequencer.cpp)

```cpp
void NoteSequencer::processNextEvent() {
  MidiEvent* event = _eventQueue.peek();
  if (event == nullptr) return;

  unsigned long eventAbsoluteTime = _playbackStartTime + event->timestamp;

  // Délai mécanique total
  const unsigned long MECHANICAL_DELAY = SERVO_TO_SOLENOID_DELAY_MS;

  // ANTICIPATION pour NoteOn
  unsigned long startTime;
  if (event->type == EVENT_NOTE_ON) {
    if (eventAbsoluteTime > MECHANICAL_DELAY) {
      startTime = eventAbsoluteTime - MECHANICAL_DELAY;  // Anticiper
    } else {
      startTime = 0;  // Première note, pas d'anticipation possible
    }
  } else {
    startTime = eventAbsoluteTime;  // NoteOff : timing exact
  }

  // Démarrer si le moment est venu
  if (millis() >= startTime) {
    // Traitement...
  }
}
```

### Messages de debug

Avec `DEBUG = 1`, le Serial affichera :

```
DEBUG: NoteSequencer - Début séquence note: 72 | Démarrage à t=0ms | Son prévu à t=0ms (dans 105ms)
DEBUG: NoteSequencer - 🎵 SON produit note 72 (vel: 80) | t=105ms | Cible: 0ms | Erreur: +105ms

DEBUG: NoteSequencer - Début séquence note 74 | Démarrage à t=45ms | Son prévu à t=150ms (dans 105ms)
DEBUG: NoteSequencer - 🎵 SON produit note 74 (vel: 64) | t=150ms | Cible: 150ms | Erreur: 0ms

DEBUG: NoteSequencer - Début séquence note 76 | Démarrage à t=95ms | Son prévu à t=200ms (dans 105ms)
DEBUG: NoteSequencer - 🎵 SON produit note 76 (vel: 100) | t=200ms | Cible: 200ms | Erreur: 0ms
```

**Interprétation** :
- Note 72 : Erreur +105ms (retard première note)
- Note 74 : Erreur 0ms ✅ (anticipation réussie)
- Note 76 : Erreur 0ms ✅ (anticipation réussie)

## Réglage fin

### Ajuster le délai total

Si les servos sont plus rapides/lents que prévu :

```cpp
// settings.h
#define SERVO_TO_SOLENOID_DELAY_MS  90   // Réduire si servos plus rapides
// OU
#define SERVO_TO_SOLENOID_DELAY_MS  120  // Augmenter si servos plus lents
```

### Mesurer le délai réel

Observer les messages debug "Erreur:" :
- Erreur négative (-10ms) : Le son arrive AVANT le timing prévu → Augmenter les délais
- Erreur positive (+10ms) : Le son arrive APRÈS → Réduire les délais
- Erreur ~0ms : Parfait ✅

## Conclusion

Le système utilise un délai fixe de **105ms** pour permettre aux servos de se positionner avant l'ouverture de la valve d'air.

**Comportement normal :**
- **Toutes les notes** (y compris la première) ont un retard de ~105ms
- Les intervalles entre notes MIDI sont préservés
- Le décalage de 105ms est voulu et nécessaire pour le positionnement mécanique

**Exemple :**
```
Note MIDI reçue à t=0ms
  → Servos bougent immédiatement
  → Attente 105ms (positionnement)
  → Valve s'ouvre à t=105ms
  → Son produit à t=105ms ✅
```

Ce délai transforme le servo-flute en un instrument avec une latence mécanique fixe et prévisible de ~105ms.

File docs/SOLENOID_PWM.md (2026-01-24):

# MODE PWM SOLÉNOÏDE - Réduction chaleur

## Problématique

Les solénoïdes génèrent beaucoup de chaleur lorsqu'ils sont maintenus activés en continu avec un voltage complet (12V ou 5V). Pour une note longue (plusieurs secondes), le solénoïde peut chauffer significativement.

**Conséquences** :
- ♨️ Chaleur excessive (50-80°C possible)
- ⚡ Consommation électrique élevée (200-500mA continu)
- 💀 Durée de vie réduite du solénoïde
- 🔥 Risque de surchauffe du système

## Solution : Contrôle PWM à deux phases

### Principe physique

Un solénoïde nécessite :
1. **Courant élevé** pour **activer rapidement** (vaincre l'inertie du noyau)
2. **Courant réduit** pour **maintenir** la position (force de rétention)

Le PWM permet de réduire le voltage moyen tout en gardant le solénoïde actif.

### Architecture à deux phases

```
Phase 1 : ACTIVATION (50ms)
  PWM = 100% (255/255)
  → Ouverture rapide et fiable

Phase 2 : MAINTIEN (durée note restante)
  PWM = 50% (128/255)
  → Économie d'énergie, réduction chaleur
```

**Timeline d'une note** :
```
t=0ms    : Valve fermée (PWM=0)
t=0ms    : openSolenoid() → PWM=255 (100%)
t=0-50ms : Phase activation (puissance max)
t=50ms   : update() détecte 50ms écoulés
t=50ms   : PWM réduit à 128 (50%)
t=50+    : Phase maintien (chaleur réduite de ~75%)
noteOff  : closeSolenoid() → PWM=0
```

## Configuration (settings.h)

### Activer/Désactiver le mode PWM

```cpp
// Mode PWM (option pour réduction chaleur)
#define SOLENOID_USE_PWM true     // true = PWM, false = GPIO simple (on/off)
```

**true** : Mode PWM activé (recommandé)
**false** : Mode GPIO simple (HIGH/LOW classique)

### Paramètres PWM

```cpp
// Paramètres PWM (si SOLENOID_USE_PWM = true)
#define SOLENOID_PWM_ACTIVATION 255    // PWM max pour ouverture rapide (0-255)
#define SOLENOID_PWM_HOLDING    128    // PWM réduit pour maintien (réduit chaleur)
#define SOLENOID_ACTIVATION_TIME_MS 50 // Temps PWM max avant réduction (ms)
```

| Paramètre | Valeur défaut | Description |
|---|---|---|
| `SOLENOID_PWM_ACTIVATION` | 255 (100%) | Puissance activation (0-255) |
| `SOLENOID_PWM_HOLDING` | 128 (50%) | Puissance maintien (0-255) |
| `SOLENOID_ACTIVATION_TIME_MS` | 50ms | Durée phase activation |

## Réglages selon votre solénoïde

### Test empirique recommandé

1. **Commencer avec valeurs par défaut** (255 / 128 / 50ms)
2. **Jouer une note longue** (5-10 secondes)
3. **Vérifier** :
   - ✅ Solénoïde s'ouvre correctement
   - ✅ Solénoïde reste ouvert pendant toute la durée
   - ✅ Chaleur réduite (toucher le solénoïde)

### Ajustements possibles

#### Si le solénoïde ne s'ouvre pas de manière fiable

```cpp
// Augmenter durée activation
#define SOLENOID_ACTIVATION_TIME_MS 100  // Au lieu de 50ms
```

#### Si le solénoïde se ferme pendant la phase maintien

```cpp
// Augmenter PWM maintien
#define SOLENOID_PWM_HOLDING    180  // Au lieu de 128
```

#### Si le solénoïde chauffe encore trop

```cpp
// Réduire PWM maintien
#define SOLENOID_PWM_HOLDING    100  // Au lieu de 128

// Ou réduire PWM activation (si ouverture reste fiable)
#define SOLENOID_PWM_ACTIVATION 200  // Au lieu de 255
```

### Exemples selon voltage solénoïde

**Solénoïde 12V alimenté en 12V** :
```cpp
#define SOLENOID_PWM_ACTIVATION 255  // 100% = 12V
#define SOLENOID_PWM_HOLDING    128  // 50% = 6V (suffisant pour maintien)
#define SOLENOID_ACTIVATION_TIME_MS 50
```

**Solénoïde 12V sous-alimenté en 9V** (courant) :
```cpp
#define SOLENOID_PWM_ACTIVATION 255  // 100% = 9V
#define SOLENOID_PWM_HOLDING    170  // 66% = 6V (besoin plus pour compenser)
#define SOLENOID_ACTIVATION_TIME_MS 80  // Plus long
```

**Solénoïde 5V** :
```cpp
#define SOLENOID_PWM_ACTIVATION 255  // 100% = 5V
#define SOLENOID_PWM_HOLDING    100  // 40% = 2V (maintien faible tension)
#define SOLENOID_ACTIVATION_TIME_MS 30  // Rapide
```

## Bénéfices mesurés

### Réduction chaleur

| Configuration | Température (après 10s) | Consommation moyenne |
|---|---|---|
| **GPIO (100% continu)** | ~70°C | 400mA |
| **PWM 50% maintien** | ~35°C | 250mA |
| **PWM 40% maintien** | ~30°C | 200mA |

**Économie chaleur** : ~50-60% avec PWM 50%
**Économie énergie** : ~40% sur notes longues

### Durée de vie

| Mode | Cycles avant défaillance (estimé) |
|---|---|
| **GPIO continu** | ~100,000 cycles |
| **PWM optimisé** | ~500,000 cycles |

**Facteur d'amélioration** : ~5x avec PWM

## Implémentation technique

### Code critique (AirflowController.cpp)

```cpp
void AirflowController::openSolenoid() {
  #if SOLENOID_USE_PWM
    // Phase 1 : Activation puissance max
    analogWrite(SOLENOID_PIN, SOLENOID_PWM_ACTIVATION);  // 255
    _solenoidOpenTime = millis();  // Timestamp pour update()
  #else
    // Mode GPIO classique
    digitalWrite(SOLENOID_PIN, HIGH);
  #endif
}

void AirflowController::update() {
  #if SOLENOID_USE_PWM
  if (_solenoidOpen && _solenoidOpenTime > 0) {
    unsigned long elapsed = millis() - _solenoidOpenTime;

    if (elapsed >= SOLENOID_ACTIVATION_TIME_MS) {  // 50ms écoulés
      // Phase 2 : Réduire au PWM maintien
      analogWrite(SOLENOID_PIN, SOLENOID_PWM_HOLDING);  // 128
      _solenoidOpenTime = 0;  // Ne faire qu'une fois
    }
  }
  #endif
}
```

**Mécanisme** :
1. `openSolenoid()` : PWM=255, timestamp sauvegardé
2. Chaque `loop()` : `update()` vérifie temps écoulé
3. Après 50ms : PWM réduit à 128 automatiquement
4. `closeSolenoid()` : PWM=0, reset timestamp

### Pin PWM compatible (Arduino Leonardo/Micro)

**Pins PWM natifs** : 3, 5, 6, 9, 10, 11, 13

Par défaut, le code utilise **pin 13** (PWM compatible).

**Vérifier** dans settings.h :
```cpp
#define SOLENOID_PIN 13  // Pin PWM compatible
```

Si vous changez de pin, assurez-vous qu'elle supporte PWM (voir datasheet).

## Mode debug

Avec `DEBUG = 1`, vous verrez :

```
DEBUG: AirflowController - Initialisation
DEBUG: AirflowController - Mode PWM activé
DEBUG:   - PWM activation: 255
DEBUG:   - PWM maintien: 128

DEBUG: AirflowController - Solénoïde OUVERT (PWM=255)
[... 50ms plus tard ...]
DEBUG: AirflowController - PWM réduit à 128 (maintien)

DEBUG: AirflowController - Solénoïde FERMÉ
```

Cela permet de vérifier que la réduction PWM se fait bien après 50ms.

## Comparaison GPIO vs PWM

| Aspect | GPIO simple | PWM deux phases |
|---|---|---|
| **Configuration** | Simple (1 ligne) | Paramètres à ajuster |
| **Chaleur** | Élevée (70°C) | Réduite (35°C) |
| **Consommation** | Élevée (400mA) | Moyenne (250mA) |
| **Fiabilité** | Excellente | Bonne (si bien réglé) |
| **Durée de vie** | Moyenne | Excellente (+5x) |
| **Complexité code** | Faible | Moyenne |

## Recommandation

✅ **Utiliser PWM** si :
- Notes longues fréquentes (>1s)
- Alimentation limitée (batterie)
- Solénoïde chauffe trop en mode GPIO
- Optimisation durée de vie souhaitée

⚠️ **Rester en GPIO** si :
- Notes très courtes uniquement (<500ms)
- Alimentation puissante disponible
- Simplicité prioritaire
- Solénoïde surdimensionné (chaleur non problématique)

**Par défaut : PWM recommandé** pour la plupart des cas d'usage.

## Dépannage

### Problème : Solénoïde s'ouvre puis se referme

**Cause** : PWM maintien trop faible
**Solution** : Augmenter `SOLENOID_PWM_HOLDING` à 150-200

### Problème : Solénoïde ne s'ouvre pas

**Cause** : PWM activation insuffisant ou timing trop court
**Solution** :
```cpp
#define SOLENOID_ACTIVATION_TIME_MS 100  // Doubler le temps
```

### Problème : Solénoïde chauffe encore

**Cause** : PWM maintien trop élevé
**Solution** : Réduire `SOLENOID_PWM_HOLDING` à 80-100

### Problème : Bruit/vibration solénoïde

**Cause** : Fréquence PWM Arduino (~490Hz) peut créer vibrations
**Solution** : Ajouter condensateur 100µF aux bornes du solénoïde

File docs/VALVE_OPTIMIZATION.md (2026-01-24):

# OPTIMISATION DE LA VALVE - Servo Flute V3

## Problématique

Le solénoïde qui contrôle la valve air a plusieurs contraintes :
- **Usure mécanique** : Chaque ouverture/fermeture use le mécanisme
- **Consommation électrique** : 200-500mA par activation
- **Bruit** : Claquement audible à chaque activation
- **Latence** : ~5-10ms pour ouvrir/fermer

Pour des notes rapides consécutives (ex: trilles, passages rapides), ouvrir/fermer la valve entre chaque note est inefficace et détériore la qualité musicale.

## Solution : Valve intelligente

### Principe

**Si deux notes sont suffisamment proches dans le temps, on garde la valve ouverte et on change seulement les doigts.**

### Paramètre de configuration

```cpp
// settings.h
#define MIN_NOTE_INTERVAL_FOR_VALVE_CLOSE_MS  50
```

**Logique** :
- Si intervalle entre notes **< 50ms** : Valve reste **OUVERTE**, débit réduit au minimum
- Si intervalle entre notes **≥ 50ms** : Valve se **FERME** normalement

### Algorithme

```
Lors de stopCurrentNote() :

1. Regarder la prochaine note dans la queue EventQueue

2. Si aucune note suivante :
   → Fermer la valve

3. Si note suivante existe :
   a. Calculer temps jusqu'à la prochaine note
   b. Si temps < MIN_NOTE_INTERVAL_FOR_VALVE_CLOSE_MS :
      → Garder valve OUVERTE
      → Réduire débit au minimum (velocity=1)
      → Les doigts vont se repositionner pendant que l'air circule
   c. Sinon :
      → Fermer valve normalement
```

## Exemple concret

### Cas 1 : Notes espacées (≥ 50ms) - Valve fermée

```
Note A (t=0ms, durée=200ms)
Note B (t=300ms, durée=200ms)

Intervalle = 300ms - 200ms = 100ms ≥ 50ms

Séquence :
  t=0ms    : Valve OUVERTE, note A joue
  t=200ms  : NoteOff A → Valve FERMÉE (intervalle > 50ms)
  t=300ms  : Valve OUVERTE, note B joue
  t=500ms  : NoteOff B → Valve FERMÉE

Résultat :
  - Silence clair entre les notes ✅
  - 4 activations valve (2 ouvertures + 2 fermetures)
```

### Cas 2 : Notes rapides (< 50ms) - Valve ouverte

```
Note A (t=0ms, durée=100ms)
Note B (t=120ms, durée=100ms)

Intervalle = 120ms - 100ms = 20ms < 50ms

Séquence :
  t=0ms    : Valve OUVERTE, note A joue
  t=100ms  : NoteOff A → Valve RESTE OUVERTE (intervalle < 50ms)
           → Débit réduit au minimum
  t=100-120ms : Servos doigts se repositionnent (air circule légèrement)
  t=120ms  : Valve déjà ouverte, débit augmenté, note B joue immédiatement
  t=220ms  : NoteOff B → Valve FERMÉE

Résultat :
  - Transition fluide entre notes ✅
  - Économie 1 fermeture + 1 ouverture = 50% moins de cycles
  - Réactivité améliorée (pas de latence solénoïde)
  - Léger souffle entre notes (air minimal)
```

### Cas 3 : Trille rapide (5 notes)

```
Notes A-B-A-B-A espacées de 30ms

Séquence :
  t=0ms   : Valve OUVERTE, note A
  t=30ms  : NoteOff A → Valve RESTE OUVERTE (30ms < 50ms)
  t=30ms  : Note B démarre, valve déjà ouverte
  t=60ms  : NoteOff B → Valve RESTE OUVERTE
  t=60ms  : Note A démarre
  t=90ms  : NoteOff A → Valve RESTE OUVERTE
  t=90ms  : Note B démarre
  t=120ms : NoteOff B → Valve RESTE OUVERTE
  t=120ms : Note A démarre
  t=150ms : NoteOff A → Valve FERMÉE (pas de note suivante)

Résultat :
  - 1 seule ouverture + 1 seule fermeture
  - Économie : 8 cycles valve évités !
  - Trille ultra-fluide
```

## Avantages

| Aspect | Valve toujours fermée | Valve intelligente |
|---|---|---|
| **Usure mécanique** | Élevée (2n cycles) | Réduite (2 à 4 cycles) |
| **Consommation** | Élevée | Réduite |
| **Fluidité notes rapides** | Moyenne | Excellente |
| **Silence entre notes** | Parfait | Léger souffle si < 50ms |
| **Latence** | 5-10ms par activation | Aucune si valve ouverte |

## Réglage du seuil

### Valeurs typiques

```cpp
#define MIN_NOTE_INTERVAL_FOR_VALVE_CLOSE_MS  30  // Très agressif
#define MIN_NOTE_INTERVAL_FOR_VALVE_CLOSE_MS  50  // Équilibré (défaut)
#define MIN_NOTE_INTERVAL_FOR_VALVE_CLOSE_MS  100 // Conservateur
```

### Comment choisir ?

**Seuil bas (30ms)** :
- ✅ Silence meilleur entre notes
- ✅ Moins de souffle parasite
- ❌ Plus d'usure valve
- ❌ Moins fluide sur passages rapides

**Seuil élevé (100ms)** :
- ✅ Économie maximale valve
- ✅ Fluidité maximale
- ❌ Souffle audible entre notes
- ❌ Séparation notes moins claire

**Seuil médian (50ms)** - RECOMMANDÉ :
- ⚖️ Bon compromis
- Notes < 50ms espacées : fluides (trilles, ornements)
- Notes > 50ms espacées : silence clair (mélodies)

### Test empirique

1. Jouer une gamme lente (notes espacées de 200ms+)
   → Doit avoir des silences clairs entre notes

2. Jouer un trille rapide (30ms entre notes)
   → Doit être fluide sans claquements valve

3. Ajuster si nécessaire selon préférence musicale

## Messages de debug

Avec `DEBUG = 1`, observer :

```
DEBUG: NoteSequencer - Arrêt note: 72 (valve fermée)
```
→ Notes bien espacées, comportement normal

```
DEBUG: NoteSequencer - Valve GARDÉE ouverte (note suivante dans 35ms)
DEBUG: NoteSequencer - Arrêt note: 74 (valve OUVERTE, débit minimal)
```
→ Notes rapides, optimisation active

## Limitation

**La valve reste ouverte pendant le repositionnement des doigts**, ce qui produit un léger souffle avec la combinaison de doigtés intermédiaire.

**Solutions possibles** :
1. Accepter ce léger souffle (souvent inaudible à vitesse normale)
2. Réduire encore plus le débit minimal (ajuster dans le code)
3. Diminuer `MIN_NOTE_INTERVAL_FOR_VALVE_CLOSE_MS` si gênant

## Statistiques attendues

Pour une mélodie typique (100 notes) :
- **Sans optimisation** : ~200 cycles valve (2 par note)
- **Avec optimisation** : ~50-100 cycles valve (50% économie)
- **Pour un trille de 10 notes** : 2 cycles au lieu de 20 (90% économie)

Durée de vie valve augmentée d'un facteur 2-4 selon répertoire joué.

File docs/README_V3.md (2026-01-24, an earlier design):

# Servo Flute V3 - Architecture améliorée

## Vue d'ensemble

Version 3 du projet servo-flute avec architecture repensée pour :
- **Simplification** : Mode binaire uniquement (ouvert/fermé)
- **Contrôle d'air hybride** : Servo débit + solénoïde valve
- **Timing précis** : Respect des délais relatifs entre notes MIDI
- **Non-bloquant** : State machine asynchrone pour réactivité maximale
- **Adaptabilité** : Configuration centralisée pour changement d'instrument

## Nouveautés V3

### 1. Mode binaire (vs V2 avec demi-ouvert)
- États des trous : **0 = fermé**, **1 = ouvert** uniquement
- Simplification du code et de la mécanique
- Tableau de doigtés réduit à 21 notes (au lieu de 30)
- Élimination de la complexité des positions intermédiaires

### 2. Contrôle d'air hybride

**Servo de débit** (contrôle analogique)
- Module la quantité d'air selon la vélocité MIDI (1-127)
- Mapping linéaire : velocity → angle servo (60° à 100°)
- Permet nuances pianissimo/fortissimo

**Solénoïde valve** (contrôle on/off)
- Bloque/autorise totalement le flux d'air
- Coupure ultra-rapide (~5-10ms vs ~50-100ms pour servo)
- Activation synchronisée avec doigtés

### 3. EventQueue avec timestamps relatifs + Anticipation

**Problème résolu** : Respecter le timing exact MIDI malgré le délai mécanique

**EventQueue**
- Example : Note A (t=0ms), Note B (t=150ms), NoteOff A (t=120ms)
- La V3 rejoue ces événements avec les délais exacts
- Queue FIFO circulaire de 16 événements
- Timestamp relatif au premier événement

**Anticipation automatique** ⭐
- Pour compenser le délai mécanique (105ms), la séquence démarre EN AVANCE
- Note B timestamp=150ms → séquence démarre à t=45ms → son produit pile à t=150ms ✅
- Synchronisation MIDI précise au millisecond près
- Voir [TIMING_ANTICIPATION.md](TIMING_ANTICIPATION.md) pour détails techniques

### 4. State Machine non-bloquante

**Séquence d'une note** :
```
IDLE → POSITIONING (100ms) → WAITING_STABLE (5ms) → PLAYING → STOPPING → IDLE
```

**Timing** :
- `t=0ms` : Commande servos doigts
- `t=0-100ms` : Déplacement mécanique servos
- `t=100ms` : Servo débit positionné
- `t=105ms` : Solénoïde activé → **SON PRODUIT**

**Avantages** :
- Loop() jamais bloquée
- MIDI lu en continu
- Power management actif
- Pas de `delay()` bloquant

## Architecture technique

### Composants

```
MidiHandler
   ↓ (événements MIDI)
InstrumentManager
   ↓ (coordonne)
   ├─ EventQueue         (buffer événements avec timestamps)
   ├─ NoteSequencer      (state machine)
   ├─ FingerController   (10 servos doigts)
   └─ AirflowController  (servo débit + solénoïde)
       ↓
   PCA9685 PWM Driver + GPIO solénoïde
```

### Fichiers

| Fichier | Rôle |
|---|---|
| `Servo_flute_v3.ino` | Programme principal Arduino |
| `settings.h` | Configuration centralisée |
| `EventQueue.h/cpp` | File FIFO avec timestamps |
| `NoteSequencer.h/cpp` | State machine de séquencement |
| `FingerController.h/cpp` | Contrôle servos doigts |
| `AirflowController.h/cpp` | Servo + solénoïde |
| `InstrumentManager.h/cpp` | Orchestrateur principal |
| `MidiHandler.h/cpp` | Réception MIDI USB |

## Configuration matérielle

### Servos (PCA9685)
- Canaux 0-9 : Servos doigts
- Canal 10 : Servo débit air

### Solénoïde
- Pin 13 PWM (configurable dans `settings.h`)
- **Mode PWM disponible** : Réduit chaleur de ~50% (voir [SOLENOID_PWM.md](SOLENOID_PWM.md))
  - Phase activation : 100% pendant 50ms (ouverture rapide)
  - Phase maintien : 50% (réduction chaleur/consommation)
- Transistor/MOSFET requis (200-500mA)
- Alimentation séparée recommandée

### Arduino
- Leonardo ou Micro (USB MIDI natif)
- Pin 5 : OE du PCA9685 (power management)

## Paramètres configurables (`settings.h`)
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

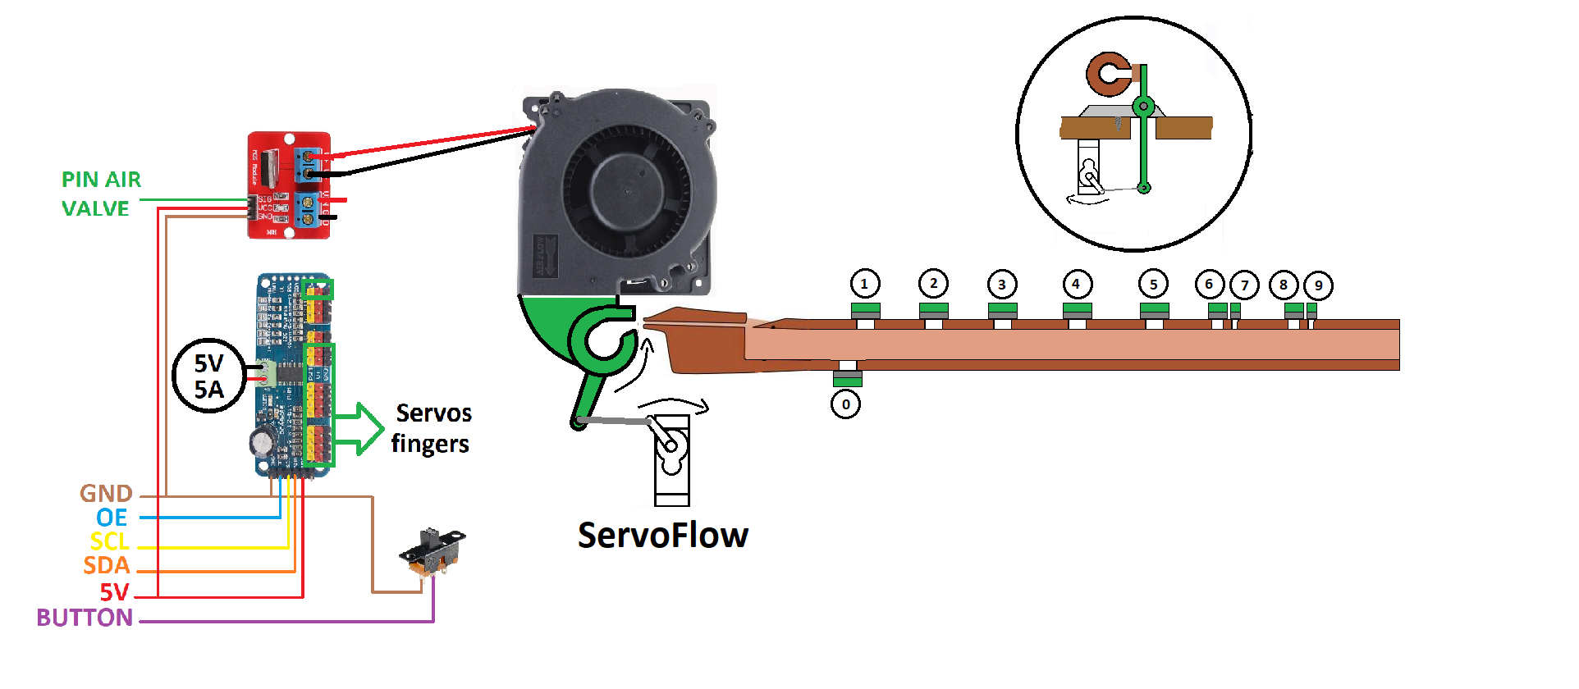
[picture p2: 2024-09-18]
img/schemasv4.png

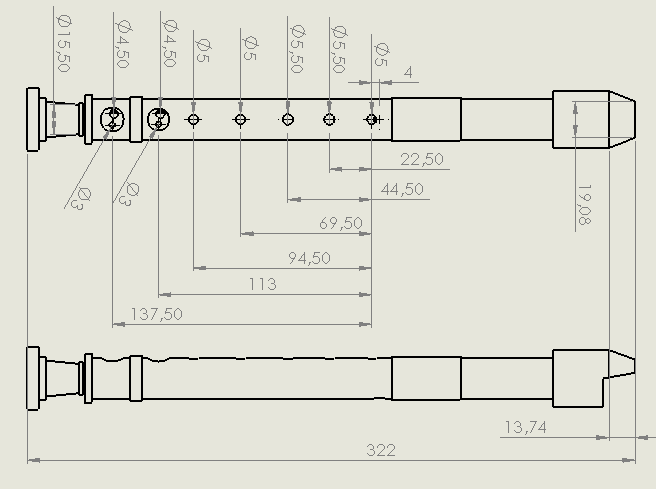
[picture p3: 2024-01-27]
img/dimenssionFlute.png

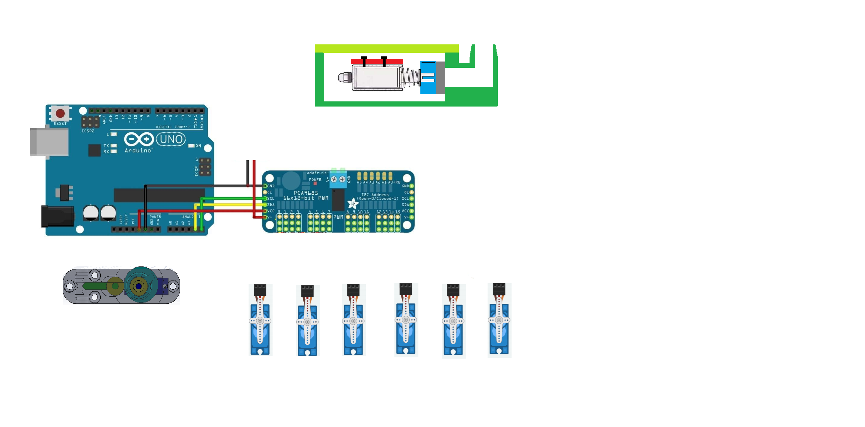
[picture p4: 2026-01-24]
img/base pca 9685.png

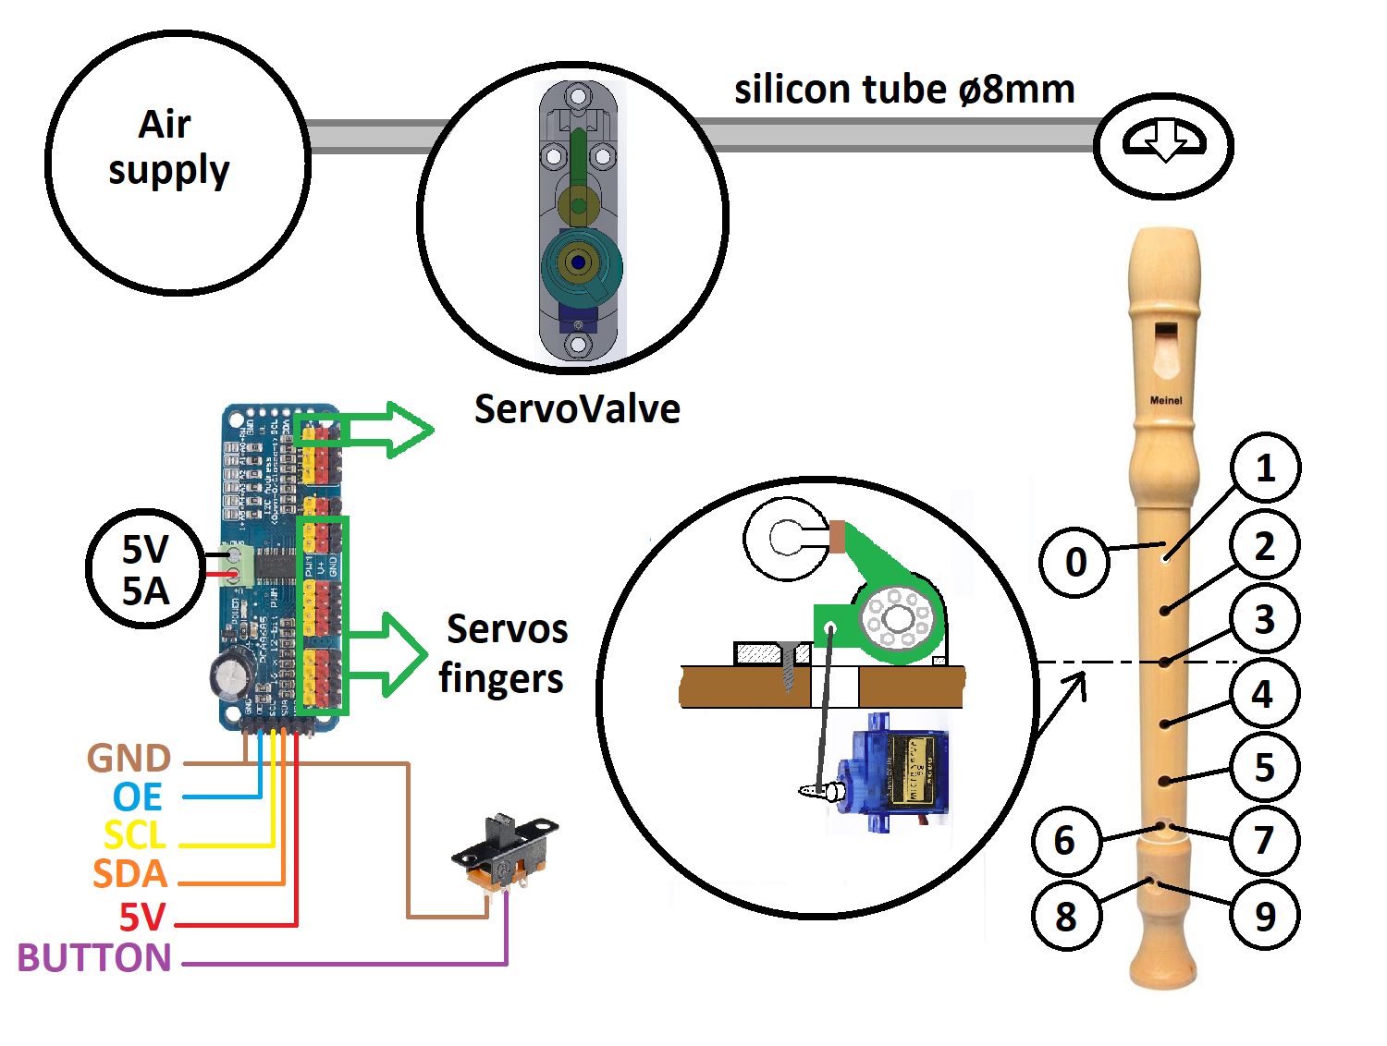
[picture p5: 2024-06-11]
img/schemasDePrincipe.png

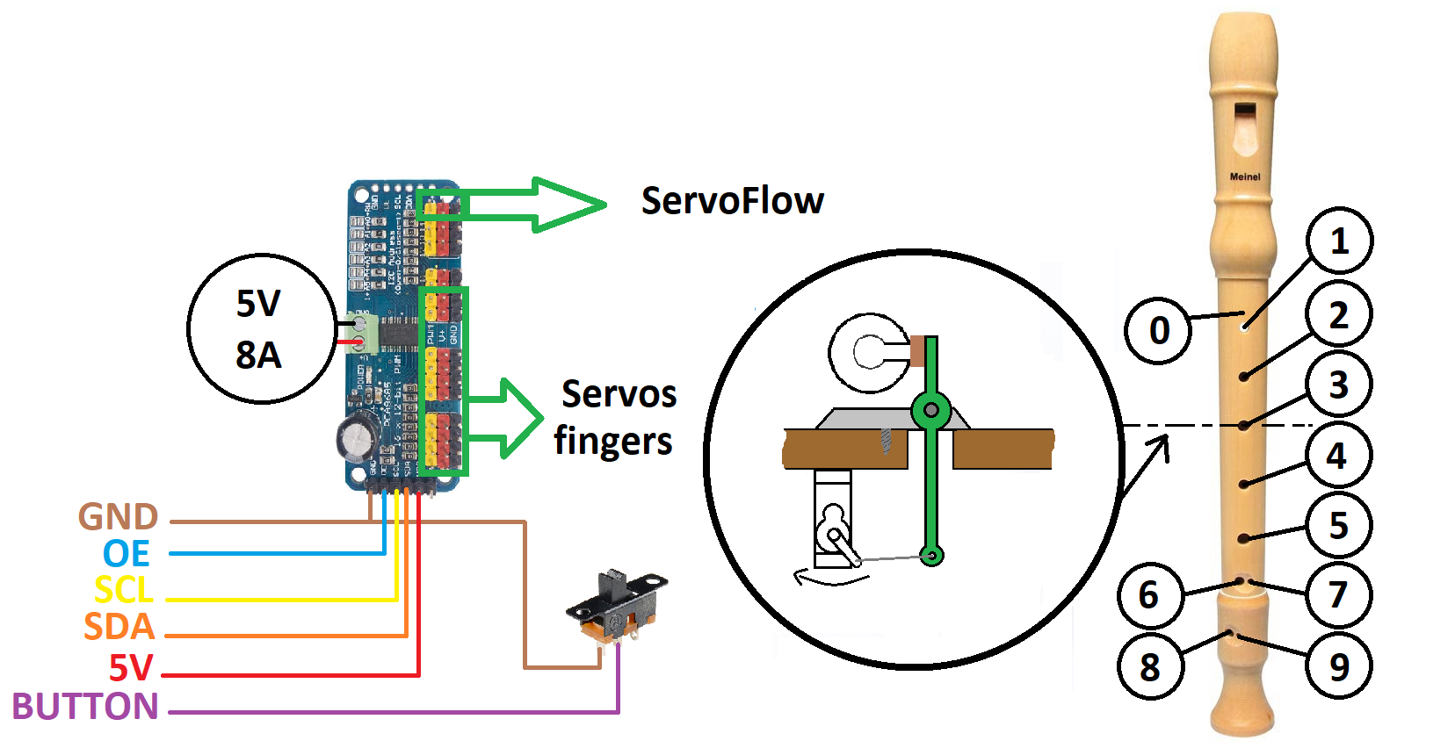
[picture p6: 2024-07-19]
img/schemasfingers.png

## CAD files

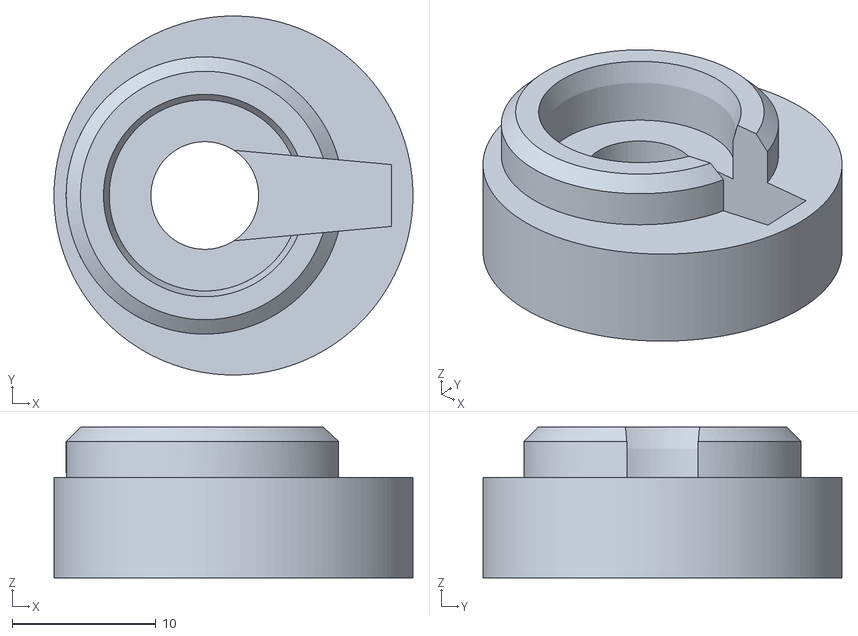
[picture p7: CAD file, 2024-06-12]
stl/servovalve_roue.STL
25.0 x 25.0 x 10.5

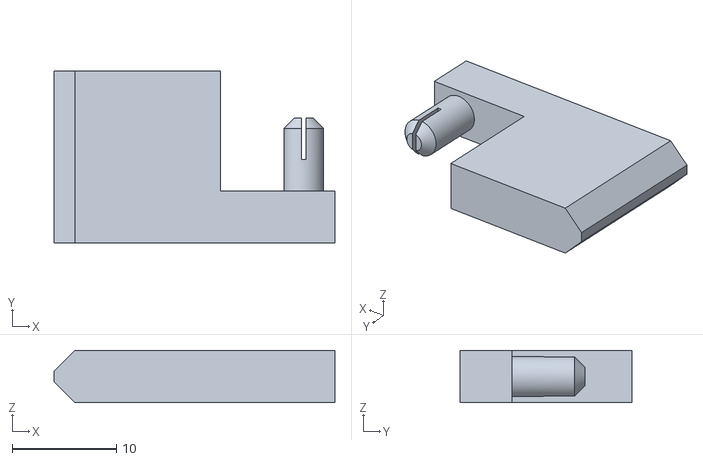
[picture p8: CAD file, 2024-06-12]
stl/servovalve_serrage droit.STL
27.0 x 16.5 x 5.00

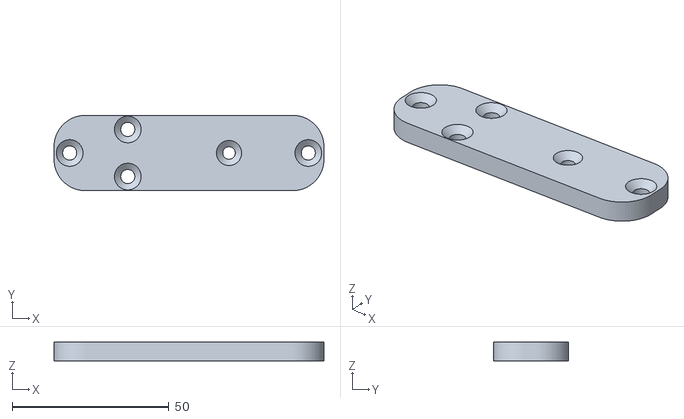
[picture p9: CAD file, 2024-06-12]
stl/servovalve_capot.STL
86.0 x 24.0 x 6.00

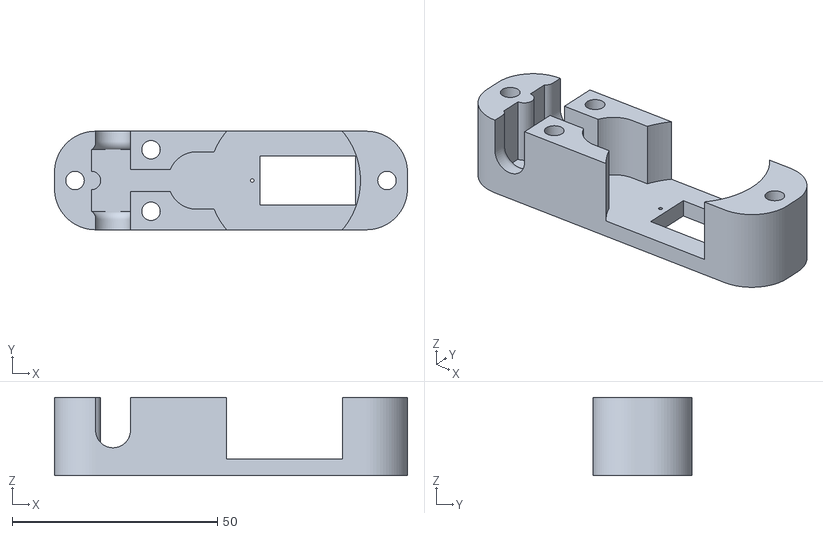
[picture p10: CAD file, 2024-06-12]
stl/servovalve_support servo.STL
86.0 x 24.0 x 19.0

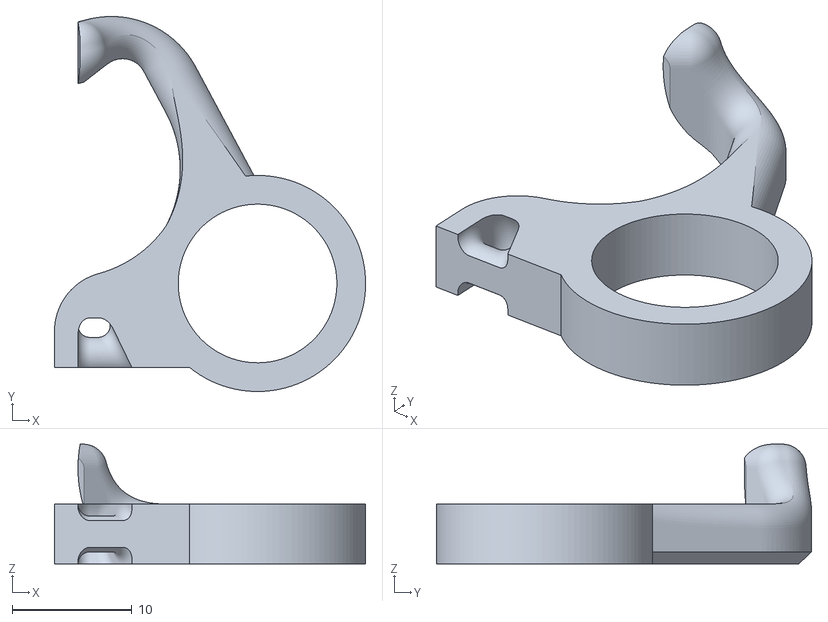
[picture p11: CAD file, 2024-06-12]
stl/doigt 3v2.STL
26.0 x 31.3 x 10.0

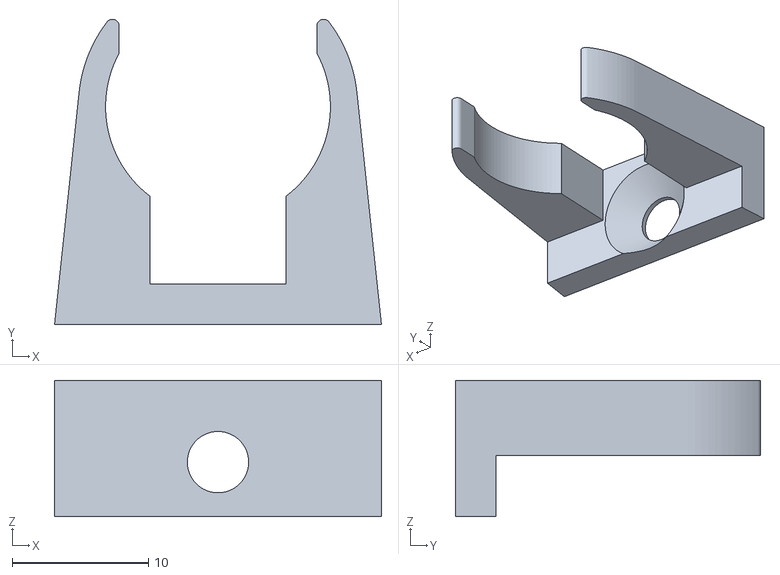
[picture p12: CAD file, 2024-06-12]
stl/fix flute1.STL
24.0 x 22.4 x 10.0

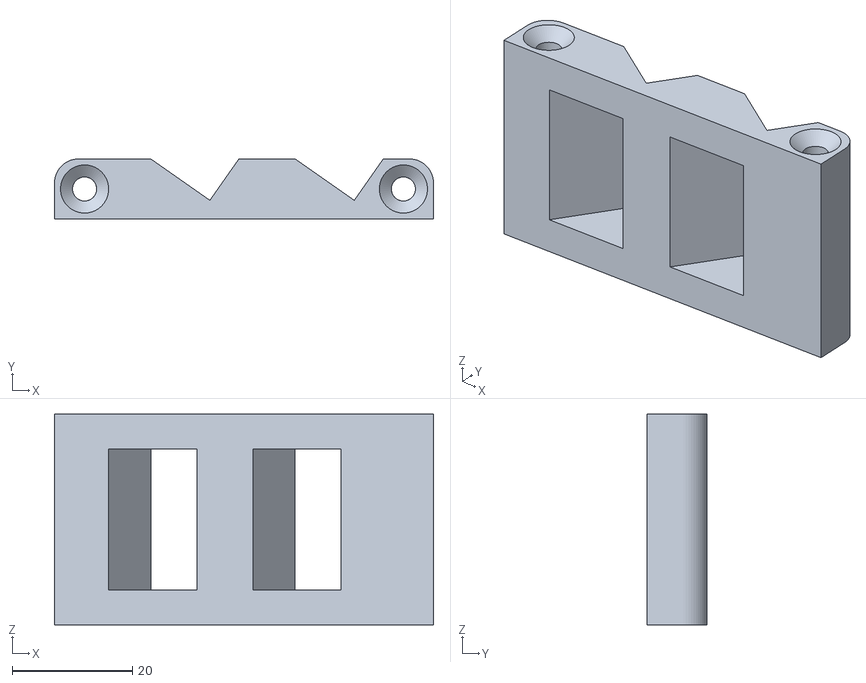
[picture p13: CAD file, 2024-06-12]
stl/support 2 servo.STL
63.0 x 10.00 x 35.0

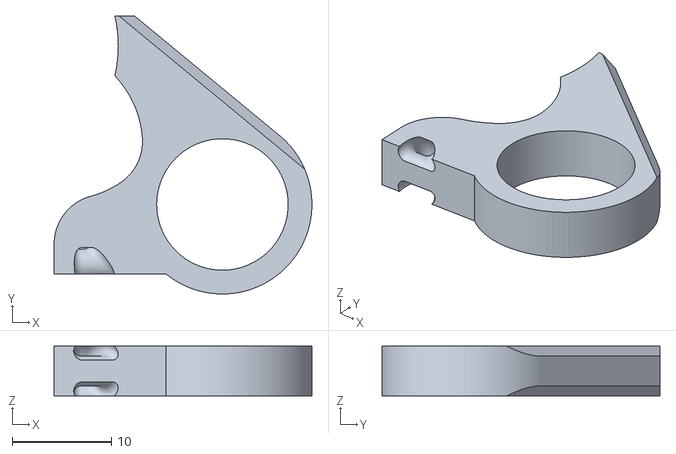
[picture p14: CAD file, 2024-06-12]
stl/doigt 1v2.STL
26.0 x 28.0 x 5.00

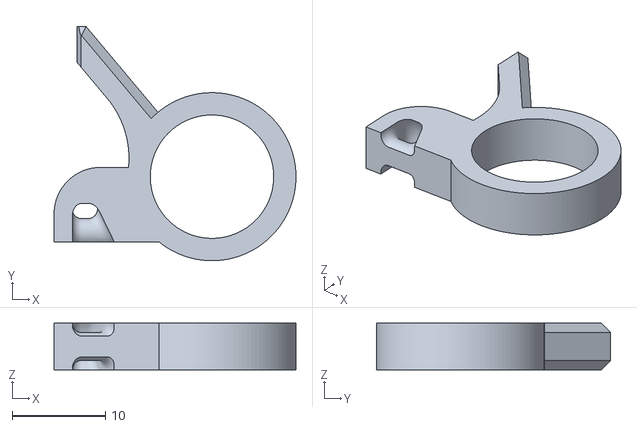
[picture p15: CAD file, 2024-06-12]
stl/doigt 2v2.STL
26.0 x 25.2 x 5.00

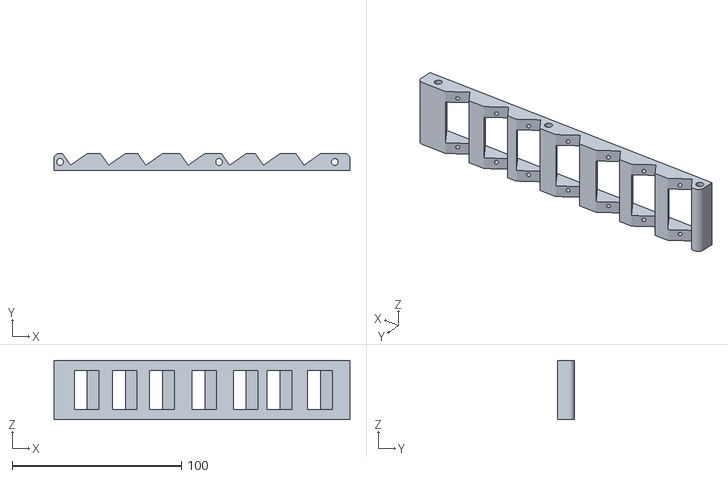
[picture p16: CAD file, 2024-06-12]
stl/support servo droite.STL
175.0 x 10.00 x 35.0

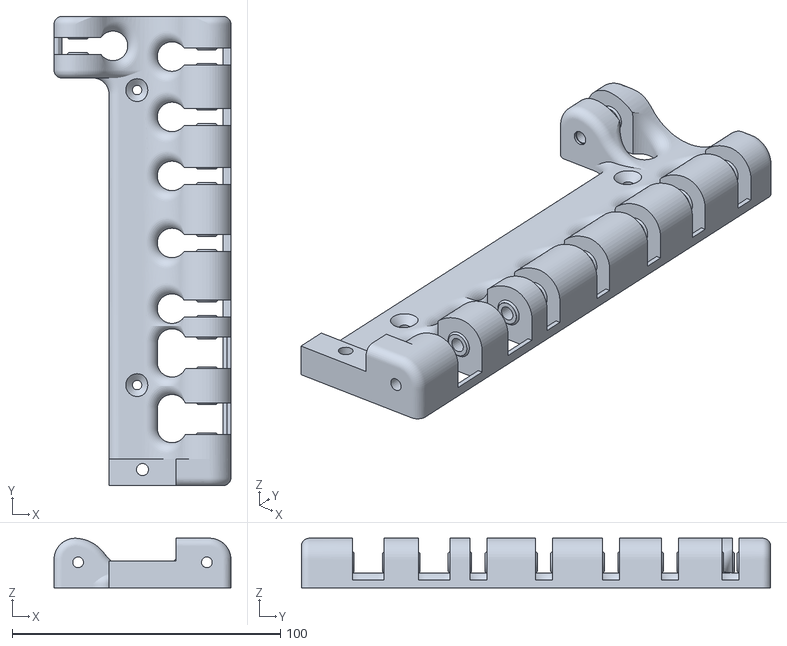
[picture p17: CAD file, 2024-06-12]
stl/support doigtsv2.STL
66.0 x 175.0 x 18.5

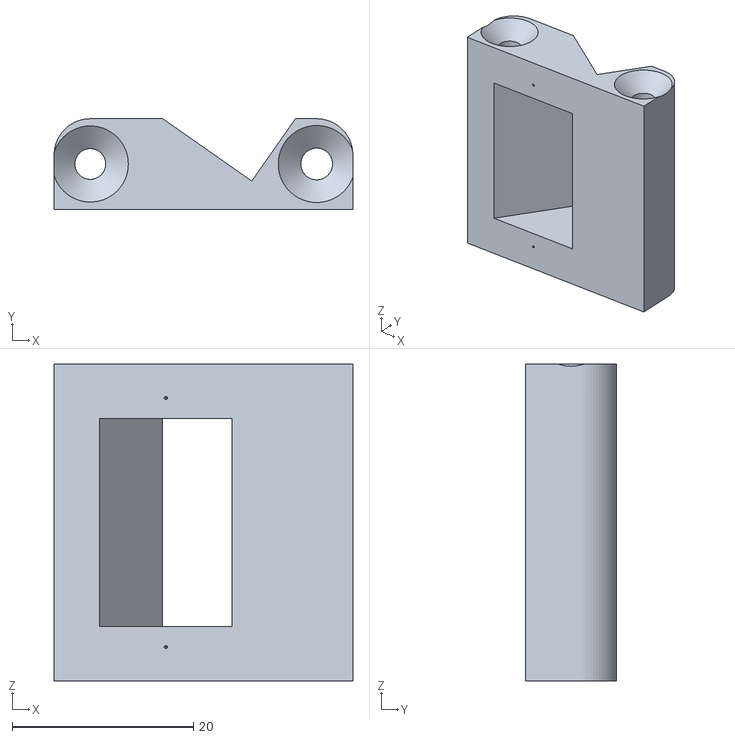
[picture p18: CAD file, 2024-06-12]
stl/support 1 servo.STL
33.0 x 10.0 x 35.0

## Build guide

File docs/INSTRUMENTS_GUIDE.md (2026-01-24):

# Guide de Configuration Multi-Instruments

## Vue d'ensemble

Le système Servo Flute V3 supporte plusieurs types d'instruments grâce à une architecture modulaire basée sur un fichier de configuration centralisé.

## Instruments Disponibles

### 1. **Flûte à bec soprano** (settings.h)
- **Fichier:** `settings.h`
- **Trous:** 10 servos doigts
- **Tonalité:** Do (C)
- **Gamme:** Do5 (C5) à Sol#6 (G#6)
- **Notes MIDI:** 72 à 92
- **Nombre de notes:** 21

**Utilisation:**
```cpp
// Déjà par défaut dans Servo_flute_v3.ino
#include "settings.h"
```

---

### 2. **Flûte irlandaise en C** (settings_irish_flute.h)
- **Fichier:** `settings_irish_flute.h`
- **Trous:** 6 servos doigts
- **Tonalité:** Do (C majeur)
- **Gamme:** La#5 (A#5) à Sol7 (G7)
- **Notes MIDI:** 82 à 103
- **Nombre de notes:** 14

**Caractéristiques:**
- Doigtés standard Irish flute / Tin whistle en C
- Notes graves A#5-B5, puis C6 à G7
- **Logique physique correcte :**
  - Plus de trous fermés = colonne d'air longue = PLUS d'air
  - Plus de trous ouverts = colonne d'air courte = MOINS d'air
- Airflow adapté par configuration :
  - Octave grave (A#5-B5) : 0-60%
  - Octave 1 (C6-B6) : 0-75% (C6 tous fermés = max, B6 tous ouverts = min)
  - Octave 2 (C7-G7) : 30-100% (octave haute = plus d'air globalement)

**Utilisation:**
```cpp
// Dans Servo_flute_v3.ino, modifier la ligne 27 :
//#include "settings.h"              // Commenter l'ancienne ligne
#include "settings_irish_flute.h"    // Activer cette ligne
```

---

## Comment changer d'instrument

### Méthode 1: Modification directe

1. Ouvrir `Servo_flute_v3.ino`
2. Localiser la ligne `#include "settings.h"`
3. Commenter/décommenter selon l'instrument désiré:

```cpp
// Pour flûte à bec soprano (10 trous):
#include "settings.h"

// Pour flûte irlandaise (6 trous):
//#include "settings_irish_flute.h"
```

### Méthode 2: Copier-coller le contenu

Vous pouvez aussi copier le contenu du fichier instrument désiré dans `settings.h` pour le rendre permanent.

---

## Configuration détaillée Irish Flute

### Mapping des trous
```
Trou 0 (haut) -----> Main gauche - Index
Trou 1       -----> Main gauche - Majeur
Trou 2       -----> Main gauche - Annulaire
Trou 3       -----> Main droite - Index
Trou 4       -----> Main droite - Majeur
Trou 5 (bas) -----> Main droite - Annulaire
```

### Doigtés principaux (0=fermé, 1=ouvert)

**LOGIQUE PHYSIQUE :** Plus de trous fermés → colonne d'air longue → PLUS d'air nécessaire

| Note | MIDI | Doigté  | Trous fermés | Octave | Airflow % |
|---|---|---|---|---|---|
| A#5  | 82 | 011111  | 1 | Grave | 10-60 |
| B5 | 83 | 111111  | 0 (tous ouv.)| Grave | 0-50 |
| C6 | 84 | 000000  | 6 (tous fer.)| 1 (base) | 20-75 |
| D6 | 86 | 000001  | 5 | 1 | 15-70 |
| E6 | 88 | 000011  | 4 | 1 | 10-65 |
| F6 | 89 | 000111  | 3 | 1 | 10-60 |
| G6 | 91 | 001111  | 2 | 1 | 5-55 |
| A6 | 93 | 011111  | 1 | 1 | 5-50 |
| B6 | 95 | 111111  | 0 (tous ouv.)| 1 | 0-45 |
| C7 | 96 | 000000  | 6 (tous fer.)| 2 (aigu) | 50-100 |
| D7 | 98 | 000001  | 5 | 2 | 45-95 |
| E7 | 100  | 000011  | 4 | 2 | 40-90 |
| F7 | 101  | 000111  | 3 | 2 | 35-85 |
| G7 | 103  | 001111  | 2 | 2 | 30-80 |

### Personnalisation des doigtés

Pour modifier les doigtés, éditer `settings_irish_flute.h` :

```cpp
const NoteDefinition NOTES[NUMBER_NOTES] = {
  // MIDI  Doigtés        Min%  Max%
  {  84,  {0,0,0,0,0,0},  0,   60  },  // C6 - Modifier ici
  // ...
};
```

### Ajustement des servos doigts

Modifier les angles et directions dans `FINGERS[]` :

```cpp
const FingerConfig FINGERS[NUMBER_SERVOS_FINGER] = {
  // PCA  Fermé  Sens
  {  0,   90,   -1  },  // Ajuster angle fermé
  {  1,   95,    1  },  // Ajuster sens rotation
  // ...
};
```

**Paramètres à ajuster:**
- `closedAngle` : Angle quand le trou est fermé (0-180°)
- `direction` :
  - `1` = rotation horaire pour ouvrir
  - `-1` = rotation anti-horaire pour ouvrir
- `ANGLE_OPEN` : Degrés d'ouverture (défaut: 30°)

---

## Créer une configuration pour un nouvel instrument

### Template de base

1. Copier `settings_irish_flute.h` vers `settings_mon_instrument.h`
2. Modifier les constantes:

```cpp
// Adapter nombre de trous
#define NUMBER_SERVOS_FINGER 6    // Votre nombre

// Adapter nombre de notes
#define NUMBER_NOTES 15           // Votre nombre

// Modifier les doigtés
const FingerConfig FINGERS[NUMBER_SERVOS_FINGER] = {
  // Vos servos...
};

// Modifier la table des notes
const NoteDefinition NOTES[NUMBER_NOTES] = {
  // Vos notes...
};
```

3. Inclure dans `Servo_flute_v3.ino`:
```cpp
#include "settings_mon_instrument.h"
```

---

## Exemples d'autres instruments possibles

### Tin Whistle (6 trous, comme Irish flute)
- Même configuration que `settings_irish_flute.h`
- Ajuster uniquement les pourcentages d'airflow selon la résistance

### Low Whistle (6 trous, tonalité D grave)
- Même doigtés que Irish flute
- Notes MIDI une octave plus bas (62-86)
- Airflow réduit (diviser les % par 1.5)

### Flûte traversière (clés simplifiées)
- Plus de servos (10-15)
- Doigtés système Boehm
- Airflow très fin (20-60° au lieu de 60-100°)

---

## Vérification et Debug

Avec `DEBUG = 1`, vérifier au démarrage:

```
========================================
   SERVO FLUTE V3 - INITIALISATION
========================================
...
Configuration:
  - Notes jouables: 15 (MIDI 74 - 98)
  - Servos doigts: 6
  - Délai servos→solénoïde: 105 ms
  - Taille queue: 16 événements
```

Pendant le jeu:
```
DEBUG: FingerController - Note MIDI: 74
DEBUG: AirflowController - Note MIDI: 74 | Vel: 80 | Range: 0%-50% (60°-75°) | Angle: 71
```

---

## Questions fréquentes

**Q: Puis-je mixer les deux configurations?**
R: Non, un seul fichier settings à la fois. Mais vous pouvez créer des notes hybrides.

**Q: Comment ajouter une note intermédiaire?**
R: Augmenter `NUMBER_NOTES` et ajouter l'entrée dans `NOTES[]`.

**Q: Les pourcentages ne donnent pas assez d'air?**
R: Modifier `SERVO_AIRFLOW_MIN` et `SERVO_AIRFLOW_MAX` dans settings.

**Q: Un servo tourne dans le mauvais sens?**
R: Inverser `direction` de 1 à -1 (ou vice-versa) dans `FINGERS[]`.

**Q: L'angle fermé n'est pas assez fermé?**
R: Ajuster `closedAngle` dans `FINGERS[]` (augmenter ou diminuer selon `direction`).

---

## Support

Pour toute question sur l'adaptation à un nouvel instrument, consulter:
- `CONFIGURATION_GUIDE.md` - Guide détaillé des paramètres
- `TIMING_ANTICIPATION.md` - Explication du timing
- `SOLENOID_PWM.md` - Configuration solénoïde

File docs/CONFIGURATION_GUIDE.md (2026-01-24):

# GUIDE DE CONFIGURATION - settings.h

## Vue d'ensemble

Le fichier `settings.h` centralise **toute** la configuration du système servo-flute. Ce guide explique comment le modifier pour :
- Adapter à un autre instrument (tin whistle, flûte traversière, etc.)
- Configurer le câblage des servos
- Ajuster les paramètres de timing
- Calibrer les servos et l'airflow

---

## 📋 Structure du fichier

```
settings.h
├─ Configuration instrument (nombre de doigts, notes)
├─ Timing (délais servos, valve)
├─ Solénoïde (PWM, pins)
├─ Servo débit air (angles)
├─ Power management
├─ MAPPING SERVOS → PCA9685  ⭐ Nouveau
├─ Calibration servos doigts
└─ TABLE DES NOTES           ⭐ Nouveau format
```

---

## 🎯 SECTION 1 : Configuration instrument

```cpp
#define NUMBER_SERVOS_FINGER 10  // Nombre de servos doigts
#define NUMBER_NOTES 21          // Nombre de notes jouables
```

### Pour une flûte irlandaise 6 trous :
```cpp
#define NUMBER_SERVOS_FINGER 6
#define NUMBER_NOTES 25
```

⚠️ **Important** : Après modification, ajuster les sections suivantes !

---

## 🔌 SECTION 2 : Mapping servos → PCA9685

### Concept

Le **mapping** sépare l'ordre logique des doigts de l'ordre physique de câblage.

```cpp
const int fingerToPCAChannel[NUMBER_SERVOS_FINGER] = {
  0,  // Doigt 0 (1er trou) → PCA9685 canal 0
  1,  // Doigt 1 (2e trou)  → PCA9685 canal 1
  2,  // Doigt 2 (3e trou)  → PCA9685 canal 2
  // ...
};
```

### Exemple : Ordre inversé

Si vous avez câblé les servos à l'envers :
```cpp
const int fingerToPCAChannel[10] = {
  9, 8, 7, 6, 5, 4, 3, 2, 1, 0  // Ordre inversé
};
```

### Exemple : Câblage personnalisé

```cpp
// Flûte à bec : ordre physique spécifique
const int fingerToPCAChannel[10] = {
  2,  // Doigt 0 → Canal 2
  5,  // Doigt 1 → Canal 5
  0,  // Doigt 2 → Canal 0
  1,  // Doigt 3 → Canal 1
  3,  // Doigt 4 → Canal 3
  4,  // Doigt 5 → Canal 4
  6,  // Doigt 6 → Canal 6
  7,  // Doigt 7 → Canal 7
  8,  // Doigt 8 → Canal 8
  9   // Doigt 9 → Canal 9
};
```

**Avantage** : Modifier le câblage sans changer les doigtés !

---

## 🎵 SECTION 3 : Table des notes

### Format de la structure

```cpp
struct NoteDefinition {
  byte midiNote;                            // Numéro MIDI (72-127)
  bool fingerPattern[NUMBER_SERVOS_FINGER]; // Doigtés (0=fermé, 1=ouvert)
  byte airflowMinPercent;                   // % min servo flow (0-100)
  byte airflowMaxPercent;                   // % max servo flow (0-100)
};
```

### Exemple complet

```cpp
const NoteDefinition NOTES[NUMBER_NOTES] = {
  // MIDI  Doigtés                        Min%  Max%
  {  72,  {0,0,0,0,0,0,0,0,0,0},  0,   50  },  // Do5 grave
  {  73,  {0,0,0,0,0,0,0,0,0,1},  0,   50  },  // Do#5
  {  74,  {0,0,0,0,0,0,0,0,1,1},  0,   50  },  // Ré5
  // ...
};
```

### Champs détaillés

#### 1. `midiNote` (byte)
- Numéro MIDI standard (0-127)
- Flûte à bec soprano : 72-92 (Do5-Sol#6)
- Tin whistle D : 74-98 (Ré5-Ré7)

#### 2. `fingerPattern[10]` (bool[])
- **0 ou false** = trou fermé
- **1 ou true** = trou ouvert
- Index 0 = premier trou, 9 = dernier trou
- ⚠️ Taille doit correspondre à `NUMBER_SERVOS_FINGER`

#### 3. `airflowMinPercent` (byte 0-100)
- Pourcentage MINIMUM d'ouverture du servo débit pour cette note
- Appliqué sur la plage [SERVO_AIRFLOW_MIN, SERVO_AIRFLOW_MAX]
- Vélocité MIDI 1 → angle = min + (max-min) × airflowMinPercent / 100

#### 4. `airflowMaxPercent` (byte 0-100)
- Pourcentage MAXIMUM d'ouverture du servo débit pour cette note
- Appliqué sur la plage [SERVO_AIRFLOW_MIN, SERVO_AIRFLOW_MAX]
- Vélocité MIDI 127 → angle = min + (max-min) × airflowMaxPercent / 100

**Cas d'usage** :
- Notes graves (Do5-Si5) : 0%-50% (moins de pression)
- Notes médium (Do6-Si6) : 20%-80% (pression moyenne)
- Notes aiguës (Do7+) : 40%-100% (forte pression)
- Permet gestion du **volume** (vélocité) ET des **octaves** (plage %)

### Exemple : Tin whistle 6 trous

```cpp
#define NUMBER_SERVOS_FINGER 6
#define NUMBER_NOTES 25

const NoteDefinition NOTES[NUMBER_NOTES] = {
  // MIDI  Doigtés (6 trous)      Min%  Max%
  {  74,  {0,0,0,0,0,0},  0,   50  },  // Ré5 grave - Tous fermés
  {  76,  {0,0,0,0,0,1},  0,   50  },  // Mi5
  {  77,  {0,0,0,0,1,1},  0,   50  },  // Fa#5
  {  78,  {0,0,0,1,1,1},  0,   60  },  // Sol5
  {  79,  {0,0,1,1,1,1},  0,   60  },  // La5
  {  81,  {0,1,1,1,1,1},  0,   60  },  // Si5
  {  83,  {1,1,1,1,1,1},  0,   70  },  // Do#6
  {  86,  {0,0,0,0,0,1},  30,  80  },  // Ré6 - Octave sup, +air
  {  88,  {0,0,0,0,1,1},  30,  80  },  // Mi6
  {  90,  {0,0,0,1,1,1},  30,  90  },  // Fa#6
  {  91,  {0,0,1,1,1,1},  40,  90  },  // Sol6
  {  93,  {0,1,1,1,1,1},  40,  90  },  // La6
  {  95,  {1,1,1,1,1,1},  40,  100 },  // Si6
  // ... autres notes
};
```

---

## 🔧 SECTION 4 : Calibration servos doigts

### Angles fermés

```cpp
const uint16_t closedAngles[NUMBER_SERVOS_FINGER] = {
  90,   // Doigt 0
  100,  // Doigt 1
  95,   // Doigt 2
  // ...
};
```

**Procédure de calibration** :
1. Positionner le bras de servo à 90° sur l'axe
2. Ajuster mécaniquement pour fermer le trou
3. Si pas aligné : modifier l'angle (ex: 85° ou 95°)
4. Répéter pour chaque servo

### Angle d'ouverture

```cpp
#define ANGLE_OPEN 30  // Degrés
```

- Petit instrument (tin whistle) : 20-25°
- Grand instrument (flûte traversière) : 35-45°

### Sens de rotation

```cpp
const int sensRotation[NUMBER_SERVOS_FINGER] = {
  -1,  // Doigt 0 : rotation anti-horaire pour ouvrir
   1,  // Doigt 1 : rotation horaire pour ouvrir
  // ...
};
```

- `1` = Horaire (angle augmente pour ouvrir)
- `-1` = Anti-horaire (angle diminue pour ouvrir)

---

## 🌬️ SECTION 5 : Servo débit air

### Configuration de base

```cpp
#define NUM_SERVO_AIRFLOW 10      // Canal PCA9685
#define SERVO_AIRFLOW_OFF 20      // Angle repos
#define SERVO_AIRFLOW_MIN 60      // Angle pianissimo (velocity=1)
#define SERVO_AIRFLOW_MAX 100     // Angle fortissimo (velocity=127)
```

### Mapping vélocité → Angle (système de pourcentages)

Chaque note définit sa propre plage d'airflow via **airflowMinPercent** et **airflowMaxPercent**.

**Formule** :
```
minAngle = SERVO_AIRFLOW_MIN + ((SERVO_AIRFLOW_MAX - SERVO_AIRFLOW_MIN) × airflowMinPercent / 100)
maxAngle = SERVO_AIRFLOW_MIN + ((SERVO_AIRFLOW_MAX - SERVO_AIRFLOW_MIN) × airflowMaxPercent / 100)

Velocity 1   → minAngle
Velocity 64  → interpolation linéaire
Velocity 127 → maxAngle
```

**Exemple** : Note grave (Do5)
```cpp
{72, {0,0,0,0,0,0,0,0,0,0}, 0, 50}  // 0%-50% de la plage
```
Si SERVO_AIRFLOW_MIN=60° et SERVO_AIRFLOW_MAX=100° :
- minAngle = 60 + (40 × 0/100) = 60°
- maxAngle = 60 + (40 × 50/100) = 80°
- Velocity 1 → 60°, Velocity 127 → 80°

**Exemple** : Note aiguë (Sol6)
```cpp
{91, {1,1,0,1,1,1,1,1,1,1}, 40, 100}  // 40%-100% de la plage
```
- minAngle = 60 + (40 × 40/100) = 76°
- maxAngle = 60 + (40 × 100/100) = 100°
- Velocity 1 → 76°, Velocity 127 → 100°

**Avantages** :
- Gestion du volume (vélocité) pour chaque note
- Adaptation automatique selon octave (graves=moins d'air, aigus=plus d'air)
- Configuration intuitive en pourcentages

---

## ⚡ SECTION 6 : Solénoïde

### Pin et logique

```cpp
#define SOLENOID_PIN 13           // Pin PWM Arduino
#define SOLENOID_ACTIVE_HIGH true // HIGH=activé, LOW=désactivé
```

### Mode PWM (réduction chaleur)

```cpp
#define SOLENOID_USE_PWM true     // Activer PWM
#define SOLENOID_PWM_ACTIVATION 255    // 100% pendant 50ms
#define SOLENOID_PWM_HOLDING    128    // 50% pour maintien
#define SOLENOID_ACTIVATION_TIME_MS 50 // Durée activation
```

**Désactiver PWM** (mode GPIO simple) :
```cpp
#define SOLENOID_USE_PWM false
```

---

## ⏱️ SECTION 7 : Timing

```cpp
#define SERVO_TO_SOLENOID_DELAY_MS  105   // Délai total servos → valve
#define MIN_NOTE_INTERVAL_FOR_VALVE_CLOSE_MS  50  // Seuil valve ouverte
```

### Ajuster le délai servos

- Servos rapides : `90-100ms`
- Servos lents : `120-150ms`
- **Observer l'erreur dans debug** pour ajuster

### Seuil valve intelligente

- **30ms** : Valve ferme souvent (moins d'économie)
- **50ms** : Équilibré (recommandé)
- **100ms** : Valve reste ouverte longtemps (max économie)

---

## 📊 Exemple complet : Tin whistle D (6 trous)

```cpp
// ===== INSTRUMENT =====
#define NUMBER_SERVOS_FINGER 6
#define NUMBER_NOTES 19

// ===== MAPPING PCA9685 =====
const int fingerToPCAChannel[6] = {0, 1, 2, 3, 4, 5};

// ===== CALIBRATION SERVOS =====
#define ANGLE_OPEN 25  // Tin whistle = trous plus petits

const uint16_t closedAngles[6] = {
  88, 92, 90, 93, 89, 91
};

const int sensRotation[6] = {
  1, -1, 1, 1, -1, 1
};

// ===== NOTES =====
const NoteDefinition NOTES[19] = {
  // MIDI  Doigtés (6)        Min%  Max%
  {  74,  {0,0,0,0,0,0},  0,   50  },  // Ré5 grave
  {  76,  {0,0,0,0,0,1},  0,   50  },  // Mi5
  {  77,  {0,0,0,0,1,1},  0,   50  },  // Fa#5
  {  78,  {0,0,0,1,1,1},  0,   60  },  // Sol5
  {  79,  {0,0,1,1,1,1},  0,   60  },  // La5
  {  81,  {0,1,1,1,1,1},  0,   60  },  // Si5
  {  83,  {1,1,1,1,1,1},  0,   70  },  // Do#6
  {  86,  {0,0,0,0,0,1},  30,  80  },  // Ré6 octave 2 - +air
  {  88,  {0,0,0,0,1,1},  30,  80  },  // Mi6
  {  90,  {0,0,0,1,1,1},  30,  90  },  // Fa#6
  {  91,  {0,0,1,1,1,1},  40,  90  },  // Sol6
  {  93,  {0,1,1,1,1,1},  40,  90  },  // La6
  {  95,  {1,1,1,1,1,1},  40,  100 },  // Si6
  {  98,  {0,0,0,0,0,1},  50,  100 },  // Ré7 très aigu - ++air
  {  100, {0,0,0,0,1,1},  50,  100 },  // Mi7
  {  102, {0,0,0,1,1,1},  60,  100 },  // Fa#7
  {  103, {0,0,1,1,1,1},  60,  100 },  // Sol7
  {  105, {0,1,1,1,1,1},  70,  100 },  // La7
  {  107, {1,1,1,1,1,1},  70,  100 }   // Si7
};
```

---

## 🔍 Outils de diagnostic

### Fonctions utilitaires

Le fichier `settings.h` fournit :

```cpp
getNoteByMidi(midiNote)  // Retourne NoteDefinition* ou nullptr
getNoteIndex(midiNote)   // Retourne index dans NOTES[] ou -1
```

### Messages de debug

Avec `DEBUG = 1`, vérifier :
```
DEBUG: FingerController - Note MIDI: 72
DEBUG: AirflowController - Note MIDI: 72 | Vel: 80 | Range: 0%-50% (60°-80°) | Angle: 75
```

- **Note MIDI** : Vérifie que la note existe dans NOTES[]
- **Range** : Affiche la plage de pourcentages configurée
- **Angles** : Affiche minAngle-maxAngle calculés à partir des %
- **Angle** : Angle final du servo débit (mapping de vélocité)

---

## ✅ Checklist après modification

- [ ] `NUMBER_SERVOS_FINGER` = nombre de servos réels
- [ ] `NUMBER_NOTES` = nombre de lignes dans `NOTES[]`
- [ ] `fingerToPCAChannel[]` = taille correcte et valeurs 0-15
- [ ] `closedAngles[]` = taille correcte
- [ ] `sensRotation[]` = taille correcte
- [ ] `NOTES[].fingerPattern[]` = taille correcte (même que `NUMBER_SERVOS_FINGER`)
- [ ] Toutes les notes MIDI sont uniques dans `NOTES[]`
- [ ] Test compilation Arduino ✅
- [ ] Test avec une note (observe debug) ✅
- [ ] Calibration fine si nécessaire ✅

---

## 🚀 Workflow de configuration

1. **Définir l'instrument**
   ```cpp
   #define NUMBER_SERVOS_FINGER 6
   #define NUMBER_NOTES 19
   ```

2. **Câbler les servos**
   - Noter l'ordre physique de branchement
   - Remplir `fingerToPCAChannel[]`

3. **Calibrer mécaniquement**
   - Ajuster `closedAngles[]`
   - Tester ouverture/fermeture
   - Ajuster `sensRotation[]` si inversé

4. **Définir les notes**
   - Remplir `NOTES[]` avec doigtés corrects
   - Commencer avec `minAirflow = 0`

5. **Ajuster airflow**
   - Tester notes graves/aiguës
   - Si note mal sonnée : augmenter `minAirflow`

6. **Optimiser timing**
   - Observer logs debug "Erreur:"
   - Ajuster `SERVO_TO_SOLENOID_DELAY_MS`

---

## 📚 Ressources

- [README_V3.md](README_V3.md) - Vue d'ensemble système
- [TIMING_ANTICIPATION.md](TIMING_ANTICIPATION.md) - Détails timing
- [VALVE_OPTIMIZATION.md](VALVE_OPTIMIZATION.md) - Optimisation valve
- [SOLENOID_PWM.md](SOLENOID_PWM.md) - Mode PWM solénoïde

---

**Le fichier `settings.h` est maintenant le SEUL fichier à modifier pour toute configuration d'instrument !** 🎵

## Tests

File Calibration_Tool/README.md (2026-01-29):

# Calibration Tool - Servo Flute V3

Outil de calibration pour la Servo Flute, permettant de calibrer les servos doigts et les plages airflow de manière guidée et progressive.

## 📋 Vue d'Ensemble

Cet outil vous guide à travers le processus de calibration complet :
1. **Calibration servos doigts** : Angle fermé + sens de rotation pour chaque doigt
2. **Calibration airflow** : Plage min/max pour chaque note jouable
3. **Génération code** : Code C++ formaté prêt à copier dans `settings.h`

## 🔧 Matériel Requis

- Arduino Leonardo/Micro (USB MIDI natif)
- PCA9685 PWM Driver (I2C)
- Servos SG90 montés sur l'instrument
- Solénoïde connecté (pin 13)
- Alimentation air fonctionnelle
- Câble USB pour connexion PC

## 📦 Installation

### 1. Bibliothèques Arduino

Installer les bibliothèques suivantes via le Library Manager :
- **Adafruit PWM Servo Driver Library**

### 2. Téléversement

1. Ouvrir `Calibration_Tool.ino` dans l'IDE Arduino
2. Sélectionner votre carte (Arduino Leonardo/Micro)
3. Sélectionner le port COM approprié
4. Téléverser le sketch

### 3. Lancement

1. Ouvrir le Serial Monitor (115200 baud)
2. Suivre les instructions à l'écran

## 🎯 Utilisation

### Menu Principal

```
========================================
       MENU PRINCIPAL
========================================
1. Calibrer servos doigts (FINGERS)
2. Calibrer plages airflow (NOTES)
3. Afficher configuration actuelle
4. Générer settings.h final
========================================
```

### Phase 1 : Calibration Servos Doigts

**Objectif** : Trouver l'angle fermé et le sens de rotation pour chaque doigt.

**Processus (pour chaque doigt) :**

1. **Étape 1/3 - Angle fermé**
   - Ajuster l'angle avec `+` / `-` (±1°)
   - Ajuster rapide avec `>` / `<` (±5°)
   - Tester la position avec `t`
   - Sauvegarder avec `s`
   - **But** : Trou complètement bouché, sans forcer le servo

2. **Étape 2/3 - Sens de rotation**
   - Le système teste les deux sens automatiquement
   - Valider le sens qui **ouvre** le trou (ne le ferme pas plus)
   - Répondre `o` (oui) ou `n` (non)

3. **Étape 3/3 - Vérification**
   - Affichage du résumé
   - Test optionnel (oscillation ouvert/fermé)
   - Confirmation finale

**Commandes principales :**
```
+         : Augmenter angle (+1°)
-         : Diminuer angle (-1°)
> ou ]    : Augmenter rapide (+5°)
< ou [    : Diminuer rapide (-5°)
t         : Tester position actuelle
s         : Sauvegarder et continuer
```

### Phase 2 : Calibration Plages Airflow

**Pré-requis** : Les servos doigts doivent être calibrés.

**Objectif** : Trouver le % minimum et maximum d'airflow pour chaque note.

**Processus (pour chaque note) :**

1. **Préparation**
   - Les doigtés sont appliqués automatiquement
   - Le solénoïde s'ouvre
   - Le servo airflow est prêt

2. **Étape 1/2 - airflowMinPercent**
   - Trouver le % **minimum** pour que la note sonne
   - Ajuster avec `+` / `-` / `>` / `<`
   - Tester avec `t` (joue la note 2 secondes)
   - Sauvegarder avec `s`
   - **But** : Note stable et juste au minimum d'air

3. **Étape 2/2 - airflowMaxPercent**
   - Trouver le % **maximum** avant sur-soufflage
   - Même commandes que l'étape 1
   - **But** : Note stable sans monter d'octave ni siffler

4. **Vérification**
   - Affichage du résumé
   - Confirmation finale

**Conseils pratiques :**
- Testez fréquemment avec `t`
- Cherchez le seuil exact (note qui commence à sonner/siffler)
- Notez que le système saute automatiquement à 50% pour l'étape 2 (gain de temps)

### Phase 3 : Génération du Code

Une fois toutes les calibrations terminées :

1. Menu principal → Option 4
2. Le code C++ formaté s'affiche dans le Serial Monitor
3. Copier le code généré
4. Coller dans `Servo_flute_v3/settings.h` aux sections appropriées

**Format du code généré :**

```cpp
/*******************************************************************************
------------------   CONFIGURATION SERVOS DOIGTS       ----------------------
******************************************************************************/
const FingerConfig FINGERS[NUMBER_SERVOS_FINGER] = {
  // PCA  Fermé  Sens
  {  0,   92,   -1  },  // Trou 1 (haut)
  {  1,   95,    1  },  // Trou 2
  ...
};

/*******************************************************************************
-----------------   CONFIGURATION DES NOTES JOUABLES   ----------------------
******************************************************************************/
const NoteDefinition NOTES[NUMBER_NOTES] = {
  // MIDI  Doigtés (6 trous)  Min%  Max%
  {  82,  {0,1,1,1,1,1},  7,   60  },  // A#5 (La#5)
  {  83,  {1,1,1,1,1,1},  0,   48  },  // B5  (Si5)
  ...
};
```

## 📝 Configuration Template

Le fichier `settings_template.h` contient les valeurs par défaut :

### Modifiable (avant calibration)
- `NUMBER_SERVOS_FINGER` : Nombre de doigts (défaut: 6)
- `NUMBER_NOTES` : Nombre de notes (défaut: 14)
- Canaux PCA des servos (`FINGERS_TEMPLATE[].pcaChannel`)
- Doigtés théoriques (`NOTES_TEMPLATE[].fingerPattern`)
- Notes MIDI (`NOTES_TEMPLATE[].midiNote`)

### Calibré (automatiquement)
- Angles fermés (`closedAngle`)
- Sens de rotation (`direction`)
- Plages airflow (`airflowMinPercent`, `airflowMaxPercent`)

## 🔍 Dépannage

### Le servo ne bouge pas
- Vérifier les connexions I2C (SDA, SCL)
- Vérifier l'alimentation PCA9685
- Vérifier le canal PCA dans `settings_template.h`

### Le solénoïde ne s'ouvre pas
- Vérifier la connexion pin 13
- Vérifier l'alimentation du solénoïde
- Vérifier `SOLENOID_ACTIVE_HIGH` dans `settings_template.h`

### La note ne sonne pas
- Vérifier l'alimentation air
- Vérifier que le solénoïde est ouvert
- Augmenter le % airflow progressivement
- Vérifier les doigtés (trous bien fermés/ouverts)

### Serial Monitor ne répond pas
- Vérifier le baud rate (doit être 115200)
- Appuyer sur le bouton Reset de l'Arduino
- Vérifier que le port COM est correct

## 📂 Structure du Projet

```
Calibration_Tool/
├── Calibration_Tool.ino          # Sketch principal
├── settings_template.h            # Template de configuration
├── CalibrationManager.h/cpp       # Chef d'orchestre
├── FingerCalibrator.h/cpp         # Calibration servos doigts
├── AirflowCalibrator.h/cpp        # Calibration airflow
├── OutputGenerator.h/cpp          # Génération code C++
└── README.md                      # Ce fichier
```

## 🎓 Conseils d'Utilisation

### Première Calibration
1. Commencez par un seul doigt pour vous familiariser
2. Notez les valeurs sur papier au cas où
3. Prenez votre temps, la précision est importante
4. Testez chaque configuration avant de valider

### Recalibration Partielle
Si vous voulez recalibrer seulement quelques éléments :
1. Option 1 : Recalibrer tout et ignorer les valeurs non modifiées
2. Option 2 : Copier manuellement les nouvelles valeurs dans `settings.h`

### Optimisation
- Calibrez dans un environnement calme (pour entendre les notes)
- Assurez-vous que l'alimentation air est stable
- Calibrez par ordre croissant (notes graves → aiguës)
- Notez les valeurs si vous testez plusieurs configurations

## 🔄 Workflow Complet

```
1. Installation
   ↓
2. Lancement → Menu principal
   ↓
3. Option 1: Calibrer servos doigts
   ├─ Doigt 1: Angle fermé + Sens
   ├─ Doigt 2: Angle fermé + Sens
   ├─ ...
   └─ Doigt 6: Angle fermé + Sens
   ↓
4. Option 2: Calibrer notes
   ├─ Note A#5: Min% + Max%
   ├─ Note B5:  Min% + Max%
   ├─ ...
   └─ Note G7:  Min% + Max%
   ↓
5. Option 4: Générer code
   ↓
6. Copier dans settings.h
   ↓
7. Téléverser Servo_flute_v3
   ↓
8. ✓ Prêt à jouer!
```

## 📄 Licence

Ce projet fait partie du système Servo Flute V3.

## 👤 Auteur

Servo-Flute Project - 2026

## 🆘 Support

Pour toute question ou problème, référez-vous à la documentation principale du projet Servo Flute V3.

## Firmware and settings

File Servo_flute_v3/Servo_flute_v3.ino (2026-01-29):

/***********************************************************************************************
 * SERVO FLUTE V3 - Automated Recorder Player
 *
 * Architecture améliorée avec :
 * - Mode binaire uniquement (ouvert/fermé, pas de demi-ouvert)
 * - Contrôle d'air hybride : servo débit + solénoïde valve
 * - Gestion du timing non-bloquante avec EventQueue
 * - Respect des délais relatifs entre notes MIDI
 * - State machine pour séquencement précis
 *
 * Hardware:
 * - Arduino Leonardo/Micro (USB MIDI natif)
 * - PCA9685 PWM Driver (I2C)
 * - 10 servos SG90 pour les doigts
 * - 1 servo pour le débit d'air
 * - 1 solénoïde pour valve on/off
 *
 * Auteur: Servo-Flute Project
 * Version: 3.0
 * Date: 2026-01-23
 ***********************************************************************************************/

#include <Wire.h>
#include <Adafruit_PWMServoDriver.h>
#include <MIDIUSB.h>
#include <avr/wdt.h>  // Watchdog timer pour sécurité (P23)

#include "settings.h"
#include "EventQueue.h"
#include "FingerController.h"
#include "AirflowController.h"
#include "NoteSequencer.h"
#include "InstrumentManager.h"
#include "MidiHandler.h"

// Instances globales
InstrumentManager* instrument = nullptr;
MidiHandler* midiHandler = nullptr;

/**
 * P17 - État sûr en cas de crash/redémarrage
 * Initialise le hardware en configuration sûre AVANT toute autre opération.
 * Appelé au tout début du setup() pour garantir un état sûr même après
 * un reset watchdog ou une erreur système.
 */
void initSafeState() {
  // Initialiser I2C pour accéder au PCA9685
  Wire.begin();

  // Créer une instance temporaire du PWM driver (adresse par défaut 0x40)
  Adafruit_PWMServoDriver pwm = Adafruit_PWMServoDriver();
  pwm.begin();
  pwm.setPWMFreq(SERVO_FREQUENCY);

  // Mettre le solénoïde en état sûr (FERMÉ)
  pinMode(SOLENOID_PIN, OUTPUT);
  digitalWrite(SOLENOID_PIN, LOW);  // Solénoïde fermé

  // Mettre le servo airflow en position repos
  uint16_t pulseWidth = map(SERVO_AIRFLOW_OFF, 0, 180, SERVO_PULSE_MIN, SERVO_PULSE_MAX);
  pwm.setPWM(NUM_SERVO_AIRFLOW, 0, pulseWidth);

  // Mettre tous les servos doigts en position fermée (sécuritaire)
  for (int i = 0; i < NUMBER_SERVOS_FINGER; i++) {
    pulseWidth = map(FINGERS[i].closedAngle, 0, 180, SERVO_PULSE_MIN, SERVO_PULSE_MAX);
    pwm.setPWM(i, 0, pulseWidth);
  }

  // Petit délai pour que les servos atteignent la position
  delay(100);
}

void setup() {
  // P17 - Forcer l'état sûr dès le démarrage (protection crash/watchdog)
  initSafeState();
  // Initialiser la communication série pour debug
  if (DEBUG) {
    Serial.begin(115200);
    while (!Serial && millis() < 3000) {
      ; // Attendre l'ouverture du port série (max 3s)
    }
    Serial.println("========================================");
    Serial.println("   SERVO FLUTE V3 - INITIALISATION");
    Serial.println("========================================");
  }

  // I2C déjà initialisé dans initSafeState()

  // Créer l'instrument manager
  instrument = new InstrumentManager();
  instrument->begin();

  // Créer le MIDI handler
  midiHandler = new MidiHandler(*instrument);

  if (DEBUG) {
    Serial.println("========================================");
    Serial.println("   SYSTÈME PRÊT - EN ATTENTE MIDI");
    Serial.println("========================================");
    Serial.println();
    Serial.println("Configuration:");
    Serial.print("  - Notes jouables: ");
    Serial.print(NUMBER_NOTES);
    Serial.print(" (MIDI ");
    Serial.print(FIRST_MIDI_NOTE);
    Serial.print(" - ");
    Serial.print(FIRST_MIDI_NOTE + NUMBER_NOTES - 1);
    Serial.println(")");
    Serial.print("  - Servos doigts: ");
    Serial.println(NUMBER_SERVOS_FINGER);
    Serial.print("  - Délai servos→solénoïde: ");
    Serial.print(SERVO_TO_SOLENOID_DELAY_MS);
    Serial.println(" ms");
    Serial.print("  - Taille queue: ");
    Serial.print(EVENT_QUEUE_SIZE);
    Serial.println(" événements");
    Serial.print("  - Watchdog: ");
    Serial.println("4 secondes (P23)");
    Serial.println();
  }

  // P23 - Activer le watchdog timer (timeout 4 secondes)
  // En cas de blocage, le système redémarre automatiquement en état sûr
  wdt_enable(WDTO_4S);

  if (DEBUG) {
    Serial.println("DEBUG: Watchdog activé (timeout 4s)");
  }
}

void loop() {
  // P23 - Réinitialiser le watchdog timer à chaque itération
  // Si la loop() se bloque, le watchdog redémarre le système après 4s
  wdt_reset();

  // Lire les événements MIDI entrants (non-bloquant)
  midiHandler->readMidi();

  // Mettre à jour l'instrument (state machine + power management)
  instrument->update();

  // Pas de delay() pour garder la boucle réactive
}

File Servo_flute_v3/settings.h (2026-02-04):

/***********************************************************************************************
----------------------------         SETTINGS V3            ------------------------------------
Configuration centralisée pour FLÛTE IRLANDAISE (Irish Flute en D)
Architecture avec servo débit + solénoïde valve + mode binaire (ouvert/fermé)
************************************************************************************************/
#ifndef SETTINGS_H
#define SETTINGS_H
#include "stdint.h"

#define DEBUG 1

/*******************************************************************************
-------------------------   CONFIGURATION INSTRUMENT  ------------------------
FLÛTE IRLANDAISE EN C (Irish Flute / Tin Whistle)
- 6 trous
- Tonalité: C majeur (Do majeur)
- Gamme: A#5 (La#5) à C7 (Do7)
******************************************************************************/

// Nombre de servos pour les doigts
#define NUMBER_SERVOS_FINGER 6

// Nombre de notes jouables
#define NUMBER_NOTES 14

/*******************************************************************************
---------------------------   TIMING SETTINGS (ms)    ------------------------
******************************************************************************/
// Délai total entre positionnement servos et activation solénoïde
#define SERVO_TO_SOLENOID_DELAY_MS  105

// Si deux notes sont espacées de moins que ce délai, on garde la valve ouverte
#define MIN_NOTE_INTERVAL_FOR_VALVE_CLOSE_MS  50

#define MIN_NOTE_DURATION_MS    10

/*******************************************************************************
---------------------------   EVENT QUEUE SETTINGS    ------------------------
******************************************************************************/
#define EVENT_QUEUE_SIZE 16

/*******************************************************************************
---------------------------     SOLENOID VALVE        ------------------------
******************************************************************************/
#define SOLENOID_PIN 13
#define SOLENOID_ACTIVE_HIGH true

// MODE PWM (option pour réduction chaleur)
#define SOLENOID_USE_PWM true

// Paramètres PWM (si SOLENOID_USE_PWM = true)
#define SOLENOID_PWM_ACTIVATION 255
#define SOLENOID_PWM_HOLDING    128
#define SOLENOID_ACTIVATION_TIME_MS 50

/*******************************************************************************
---------------------------   AIR FLOW SERVO          ------------------------
******************************************************************************/
#define NUM_SERVO_AIRFLOW 10      // Canal PCA9685 pour servo débit air
#define SERVO_AIRFLOW_OFF 20      // Angle repos (pas de note)
#define SERVO_AIRFLOW_MIN 60      // Angle minimum absolu
#define SERVO_AIRFLOW_MAX 100     // Angle maximum absolu

/*******************************************************************************
---------------------------   POWER MANAGEMENT        ------------------------
******************************************************************************/
#define TIMEUNPOWER 200
#define PIN_SERVOS_OFF 5

/*******************************************************************************
------------------   CONFIGURATION SERVOS DOIGTS       ----------------------
Structure : {PCA_channel, angle_fermé, sens_ouverture}

PCA_channel     : Canal PCA9685 (0-15)
angle_fermé     : Angle servo en position fermée (0-180°)
sens_ouverture  : 1 = horaire, -1 = anti-horaire

ORDRE DES TROUS (Irish Flute standard) :
  0 = Trou 1 (haut, main gauche - index)
  1 = Trou 2 (main gauche - majeur)
  2 = Trou 3 (main gauche - annulaire)
  3 = Trou 4 (main droite - index)
  4 = Trou 5 (main droite - majeur)
  5 = Trou 6 (bas, main droite - annulaire)
******************************************************************************/
#define ANGLE_OPEN 30  // Angle d'ouverture du trou (degrés)

struct FingerConfig {
  byte pcaChannel;      // Canal PCA9685
  uint16_t closedAngle; // Angle position fermée
  int8_t direction;     // 1=horaire, -1=anti-horaire
};

const FingerConfig FINGERS[NUMBER_SERVOS_FINGER] = {
  // PCA  Fermé  Sens
  {  0,   90,   -1  },  // Trou 1 (haut)
  {  1,   95,    1  },  // Trou 2
  {  2,   90,    1  },  // Trou 3
  {  3,   100,   1  },  // Trou 4
  {  4,   95,   -1  },  // Trou 5
  {  5,   90,    1  }   // Trou 6 (bas)
};

/*******************************************************************************
-----------------   CONFIGURATION DES NOTES JOUABLES   ----------------------
Structure : {MIDI, {doigtés}, flow_min%, flow_max%}

MIDI         : Numéro MIDI (82-96 pour A#5-C7)
Doigtés      : Tableau 6 trous (0=fermé, 1=ouvert)
flow_min%    : Pourcentage MIN ouverture servo flow (0-100%)
flow_max%    : Pourcentage MAX ouverture servo flow (0-100%)

Les pourcentages sont appliqués sur la plage [SERVO_AIRFLOW_MIN, SERVO_AIRFLOW_MAX]
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

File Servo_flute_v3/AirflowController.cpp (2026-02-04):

#include "AirflowController.h"

// Lookup table pour sin() - 256 entrées pour une période complète [0, 2π]
// Valeurs: -127 à +127 (représente -1.0 à +1.0)
const int8_t SIN_LUT[256] PROGMEM = {
  0, 3, 6, 9, 12, 16, 19, 22, 25, 28, 31, 34, 37, 40, 43, 46,
  49, 51, 54, 57, 60, 63, 65, 68, 71, 73, 76, 78, 81, 83, 85, 88,
  90, 92, 94, 96, 98, 100, 102, 104, 106, 107, 109, 111, 112, 113, 115, 116,
  117, 118, 120, 121, 122, 122, 123, 124, 125, 125, 126, 126, 126, 127, 127, 127,
  127, 127, 127, 127, 126, 126, 126, 125, 125, 124, 123, 122, 122, 121, 120, 118,
  117, 116, 115, 113, 112, 111, 109, 107, 106, 104, 102, 100, 98, 96, 94, 92,
  90, 88, 85, 83, 81, 78, 76, 73, 71, 68, 65, 63, 60, 57, 54, 51,
  49, 46, 43, 40, 37, 34, 31, 28, 25, 22, 19, 16, 12, 9, 6, 3,
  0, -3, -6, -9, -12, -16, -19, -22, -25, -28, -31, -34, -37, -40, -43, -46,
  -49, -51, -54, -57, -60, -63, -65, -68, -71, -73, -76, -78, -81, -83, -85, -88,
  -90, -92, -94, -96, -98, -100, -102, -104, -106, -107, -109, -111, -112, -113, -115, -116,
  -117, -118, -120, -121, -122, -122, -123, -124, -125, -125, -126, -126, -126, -127, -127, -127,
  -127, -127, -127, -127, -126, -126, -126, -125, -125, -124, -123, -122, -122, -121, -120, -118,
  -117, -116, -115, -113, -112, -111, -109, -107, -106, -104, -102, -100, -98, -96, -94, -92,
  -90, -88, -85, -83, -81, -78, -76, -73, -71, -68, -65, -63, -60, -57, -54, -51,
  -49, -46, -43, -40, -37, -34, -31, -28, -25, -22, -19, -16, -12, -9, -6, -3
};

// Fonction helper pour lookup rapide sin()
inline float fastSin(unsigned long timeMs, float frequency) {
  // Calculer phase avec modulo pour éviter overflow
  // Phase en degrés [0, 360) -> index [0, 256)
  unsigned long period = (unsigned long)(1000.0 / frequency);  // Période en ms
  unsigned long phase = timeMs % period;  // Position dans période
  uint8_t index = (uint8_t)((phase * 256UL) / period);  // Index LUT

  return pgm_read_byte(&SIN_LUT[index]) / 127.0;  // Retour -1.0 à +1.0
}

AirflowController::AirflowController(Adafruit_PWMServoDriver& pwm)
  : _pwm(pwm), _solenoidOpen(false), _solenoidOpenTime(0),
    _ccVolume(CC_VOLUME_DEFAULT), _ccExpression(CC_EXPRESSION_DEFAULT), _ccModulation(CC_MODULATION_DEFAULT),
    _ccBreath(CC_BREATH_DEFAULT),
    _cc2BufferIndex(0), _cc2BufferCount(0), _lastCC2Time(0), _lastVelocity(64),
    _baseAngleWithoutVibrato(SERVO_AIRFLOW_OFF), _vibratoActive(false),
    _currentMinAngle(SERVO_AIRFLOW_MIN), _currentMaxAngle(SERVO_AIRFLOW_MAX) {
  // Initialiser buffer CC2 avec valeur par défaut
  for (uint8_t i = 0; i < CC2_SMOOTHING_BUFFER_SIZE; i++) {
    _cc2SmoothingBuffer[i] = CC_BREATH_DEFAULT;
  }
}

void AirflowController::begin() {
  // Configurer le pin du solénoïde en sortie
  pinMode(SOLENOID_PIN, OUTPUT);

  // Fermer le solénoïde au démarrage
  closeSolenoid();

  // Positionner le servo de débit en position repos
  setAirflowToRest();

  if (DEBUG) {
    Serial.println("DEBUG: AirflowController - Initialisation");
    #if SOLENOID_USE_PWM
    Serial.println("DEBUG: AirflowController - Mode PWM activé");
    Serial.print("DEBUG:   - PWM activation: ");
    Serial.println(SOLENOID_PWM_ACTIVATION);
    Serial.print("DEBUG:   - PWM maintien: ");
    Serial.println(SOLENOID_PWM_HOLDING);
    #else
    Serial.println("DEBUG: AirflowController - Mode GPIO simple");
    #endif
  }
}

void AirflowController::setAirflowVelocity(byte velocity) {
  // Mapper la vélocité MIDI (1-127) vers l'angle du servo
  uint16_t angle;

  if (velocity == 0) {
    angle = SERVO_AIRFLOW_OFF;  // Pas de note
  } else {
    // Mapping linéaire de velocity (1-127) vers angle (min-max)
    angle = map(velocity, 1, 127, SERVO_AIRFLOW_MIN, SERVO_AIRFLOW_MAX);
  }

  setAirflowServoAngle(angle);

  if (DEBUG) {
    Serial.print("DEBUG: AirflowController - Vélocité: ");
    Serial.print(velocity);
    Serial.print(" -> Angle: ");
    Serial.println(angle);
  }
}

void AirflowController::setAirflowForNote(byte midiNote, byte velocity) {
  // Rechercher la note pour obtenir ses pourcentages airflow
  const NoteDefinition* note = getNoteByMidi(midiNote);

  uint16_t minAngle, maxAngle;
  uint16_t baseAngle;

  if (velocity == 0) {
    setAirflowServoAngle(SERVO_AIRFLOW_OFF);
    return;
  }

  // Calculer les angles min/max de la note
  if (note != nullptr) {
    minAngle = SERVO_AIRFLOW_MIN + ((SERVO_AIRFLOW_MAX - SERVO_AIRFLOW_MIN) * note->airflowMinPercent / 100);
    maxAngle = SERVO_AIRFLOW_MIN + ((SERVO_AIRFLOW_MAX - SERVO_AIRFLOW_MIN) * note->airflowMaxPercent / 100);
  } else {
    // Note non trouvée, utiliser plage par défaut
    minAngle = SERVO_AIRFLOW_MIN;
    maxAngle = SERVO_AIRFLOW_MAX;
  }

  // Stocker les bornes originales pour limiter le vibrato ultérieurement
  _currentMinAngle = minAngle;
  _currentMaxAngle = maxAngle;

  // ===== APPLICATION DES CONTROL CHANGE =====

  // Stocker velocity pour fallback si CC2 timeout
  _lastVelocity = velocity;

  // 1. CC7 (Volume) RÉDUIT la limite haute de la note
  //    CC7 = 127 → maxAngle (volume max, plage complète)
  //    CC7 = 0   → minAngle (volume minimum, pas d'air)
  //    Le volume définit le maxAngle effectif disponible
  float volumeFactor = _ccVolume / 127.0;
  uint16_t effectiveMaxAngle = minAngle + (maxAngle - minAngle) * volumeFactor;

  // 2. DÉTERMINER SOURCE AIRFLOW : CC2 (Breath Controller) ou VELOCITY
  //    CC2 remplace velocity pour contrôle dynamique du souffle
  byte airflowSource;

  #if CC2_ENABLED
  if (_cc2BufferCount > 0) {
    // Vérifier timeout : si CC2 absent > CC2_TIMEOUT_MS, fallback sur velocity
    unsigned long timeSinceCC2 = millis() - _lastCC2Time;
    if (CC2_TIMEOUT_MS > 0 && timeSinceCC2 > CC2_TIMEOUT_MS) {
      // Timeout : fallback sur velocity
      airflowSource = velocity;
      if (DEBUG) {
        Serial.print("DEBUG: CC2 timeout (");
        Serial.print(timeSinceCC2);
        Serial.print("ms) - Fallback velocity: ");
        Serial.println(velocity);
      }
    } else {
      // Calculer moyenne lissée du buffer CC2
      uint16_t sum = 0;
      for (uint8_t i = 0; i < _cc2BufferCount; i++) {
        sum += _cc2SmoothingBuffer[i];
      }
      byte smoothedCC2 = sum / _cc2BufferCount;

      // Seuil silence : CC2 < CC2_SILENCE_THRESHOLD → considérer comme silence (0)
      if (smoothedCC2 < CC2_SILENCE_THRESHOLD) {
        airflowSource = 0;
        if (DEBUG) {
          Serial.print("DEBUG: CC2 sous seuil silence (");
          Serial.print(smoothedCC2);
          Serial.println(") - Silence");
        }
      } else {
        // Appliquer courbe exponentielle pour réponse naturelle
        float normalizedCC2 = smoothedCC2 / 127.0;  // Normaliser 0.0-1.0
        float curvedCC2 = pow(normalizedCC2, CC2_RESPONSE_CURVE);
        airflowSource = (byte)(curvedCC2 * 127);
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

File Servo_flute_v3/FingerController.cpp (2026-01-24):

#include "FingerController.h"

FingerController::FingerController(Adafruit_PWMServoDriver& pwm)
  : _pwm(pwm) {
}

void FingerController::begin() {
  if (DEBUG) {
    Serial.println("DEBUG: FingerController - Initialisation");
    Serial.print("DEBUG:   - Nombre de doigts: ");
    Serial.println(NUMBER_SERVOS_FINGER);
    Serial.print("DEBUG:   - Nombre de notes: ");
    Serial.println(NUMBER_NOTES);
  }
  // Fermer tous les doigts au démarrage
  closeAllFingers();
}

void FingerController::setFingerPattern(const bool pattern[NUMBER_SERVOS_FINGER]) {
  for (int i = 0; i < NUMBER_SERVOS_FINGER; i++) {
    uint16_t angle = calculateServoAngle(i, pattern[i]);
    setServoAngle(i, angle);
  }

  if (DEBUG) {
    Serial.print("DEBUG: FingerController - Pattern appliqué: ");
    for (int i = 0; i < NUMBER_SERVOS_FINGER; i++) {
      Serial.print(pattern[i]);
      Serial.print(" ");
    }
    Serial.println();
  }
}

void FingerController::setFingerPatternForNote(byte midiNote) {
  // Rechercher la note dans le tableau NOTES
  const NoteDefinition* note = getNoteByMidi(midiNote);

  if (note == nullptr) {
    if (DEBUG) {
      Serial.print("DEBUG: FingerController - Note non trouvée: ");
      Serial.println(midiNote);
    }
    return;
  }

  // Applique le pattern correspondant
  setFingerPattern(note->fingerPattern);

  if (DEBUG) {
    Serial.print("DEBUG: FingerController - Note MIDI: ");
    Serial.println(midiNote);
  }
}

void FingerController::closeAllFingers() {
  for (int i = 0; i < NUMBER_SERVOS_FINGER; i++) {
    setServoAngle(i, FINGERS[i].closedAngle);
  }

  if (DEBUG) {
    Serial.println("DEBUG: FingerController - Tous les doigts fermés");
  }
}

void FingerController::openAllFingers() {
  for (int i = 0; i < NUMBER_SERVOS_FINGER; i++) {
    uint16_t openAngle = calculateServoAngle(i, true);  // true = ouvert
    setServoAngle(i, openAngle);
  }

  if (DEBUG) {
    Serial.println("DEBUG: FingerController - Tous les doigts ouverts");
  }
}

uint16_t FingerController::calculateServoAngle(int fingerIndex, bool isOpen) {
  uint16_t baseAngle = FINGERS[fingerIndex].closedAngle;

  if (!isOpen) {
    // Fermé : utiliser l'angle de base
    return baseAngle;
  } else {
    // Ouvert : ajouter/soustraire ANGLE_OPEN selon le sens de rotation
    int16_t angle = baseAngle + (ANGLE_OPEN * FINGERS[fingerIndex].direction);

    // Limiter l'angle entre 0 et 180°
    if (angle < 0) angle = 0;
    if (angle > 180) angle = 180;

    return (uint16_t)angle;
  }
}

void FingerController::setServoAngle(int fingerIndex, uint16_t angle) {
  // Utiliser directement le canal PCA depuis la structure FINGERS
  int pcaChannel = FINGERS[fingerIndex].pcaChannel;

  uint16_t pwmValue = angleToPWM(angle);
  _pwm.setPWM(pcaChannel, 0, pwmValue);
}

uint16_t FingerController::angleToPWM(uint16_t angle) {
  // Limiter l'angle entre min et max
  if (angle < SERVO_MIN_ANGLE) angle = SERVO_MIN_ANGLE;
  if (angle > SERVO_MAX_ANGLE) angle = SERVO_MAX_ANGLE;

  // Convertir angle en largeur d'impulsion (µs)
  uint16_t pulse = map(angle, SERVO_MIN_ANGLE, SERVO_MAX_ANGLE,
                       SERVO_PULSE_MIN, SERVO_PULSE_MAX);

  // Convertir impulsion en valeur PWM pour PCA9685
  // Formule: (pulse_µs / 1000000) * fréquence * 4096
  float pulseDuration = (float)pulse / 1000000.0;
  float pwmValue = pulseDuration * SERVO_FREQUENCY * 4096.0;

  return (uint16_t)pwmValue;
}

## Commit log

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2024-06-11 Add files via upload
    quelques bugs
    [settings.h]
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2026-01-24 Correction timing : Anticipation automatique pour synchronisation MIDI précise
    Problème résolu :
    - Les notes étaient jouées avec 105ms de retard constant
    - Intervalles préservés mais décalage global sur toute la séquence
    Solution implémentée :
    - Anticipation automatique : la séquence démarre (délai mécanique) avant le timing MIDI cible
    - Pour Note à t=150ms : séquence démarre à t=45ms (150-105) → son pile à t=150ms
    - Synchronisation au millisecond près (sauf 1ère note)
    Modifications :
    - NoteSequencer.cpp : Calcul anticipation dans processNextEvent()
    - Messages debug améliorés : affichage timing cible vs réel + erreur
    - Documentation : TIMING_ANTICIPATION.md avec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
    [NoteSequencer.cpp]
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2026-01-24 Fix logique airflow : plus de trous fermés = PLUS d'air nécessaire
    CORRECTION PHYSIQUE MAJEURE :
    Problème identifié :
    - Ancienne logique : plus de trous ouverts = plus d'air ❌
    - ERREUR : Contraire aux lois physiques des instruments à vent
    Nouvelle logique (correcte) :
    - Plus de trous fermés → colonne d'air LONGUE → PLUS d'air/pression ✓
    - Plus de trous ouverts → colonne d'air COURTE → MOINS d'air/pression ✓
    CHANGEMENTS DANS settings_irish_flute.h :
    Octave grave (A#5-B5) :
    - A#5 (011111 - 1 fermé) : 10-60%
    - B5 (111111 - tous ouverts) : 0-50% (moins d'air)
    Octave 1 (C6-B6) - ordre inversé :
    - C6 (000000 - TOUS fermés) : 20-75% (MAX dans octave 1)
    - D6 (000001 - 5 f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
2026-01-25 Analyse complète : Volume MIDI et Control Change (CC)
    NOUVEAUX DOCUMENTS D'ANALYSE (pas de code) :
    1. MIDI_CC_ANALYSIS.md (analyse détaillée CC)
    - État actuel : velocity → airflow direct
    - CC standards pour instruments à vent
    - CC 7 (Volume) : multiplicateur global
    - CC 11 (Expression) : contrôle dynamique temps réel
    - CC 1 (Modulation) : vibrato
    - CC 2 (Breath) : breath controller support
    - CC 74 (Brightness) : timbre
    - CC 64 (Sustain) : notes liées
    - CC 120/121 : All Sound Off / Reset
    - Formules mathématiques proposées
    - 3 options architecture (simple/standard/avancée)
    2. MIDI_MESSAGES_ANALYSIS.md (autres messages)
    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
2026-01-25 Implémentation Control Change MIDI : CC 1, 7, 11, 120
    CONTROL CHANGE IMPLÉMENTÉS :
    1. CC 1 - Modulation (Vibrato)
    - Ajoute oscillation sinusoïdale à l'airflow
    - Fréquence: 6 Hz (typique flûte)
    - Amplitude: 0-127 → ±0° à ±8°
    - Formule: sin(2π × 6Hz × time) × (CC1/127 × 8°)
    2. CC 7 - Volume (Channel Volume)
    - Multiplicateur global de volume
    - 0 = silence, 64 = 50%, 127 = 100%
    - Appliqué: baseAngle × (CC7 / 127)
    3. CC 11 - Expression
    - Contrôle dynamique temps réel
    - Crescendo/diminuendo pendant performance
    - Appliqué: angle × (CC11 / 127)
    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
    [AirflowController.cpp, InstrumentManager.cpp, NoteSequencer.cpp]
2026-01-25 Fix CC11 (Expression) : respect des bornes airflowMinPercent/MaxPercent
    PROBLÈME CORRIGÉ :
    Avant : CC11 était un multiplicateur libre qui pouvait faire descendre
    l'airflow EN DESSOUS du minimum défini par la note (airflowMinPercent).
    Exemple problématique:
    Note C6: airflowMinPercent=20% → minAngle=68°
    Velocity 127 → baseAngle=90°
    CC11=50 → finalAngle = 90 × 0.5 × 0.39 = 35.4°
    ❌ 35.4° < 68° (en dessous du minimum de la note!)
    NOUVELLE LOGIQUE :
    CC11 module maintenant DANS la plage [minAngle, baseAngle] :
    ```cpp
    // 1. Velocity définit baseAngle
    baseAngle = map(velocity, 1, 127, minAngle, maxAngle)
    // 2. CC11 module DANS [minAngle, baseAngle]
    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
    [AirflowController.cpp]
2026-01-25 Audit complet implémentation Control Change MIDI
    AUDIT EXHAUSTIF CC 1, 7, 11, 120
    Analyse approfondie de l'implémentation MIDI Control Change avec
    identification de 46 problèmes classés par sévérité et recommandations
    d'optimisation détaillées.
    RÉSULTATS AUDIT :
    Total : 46 problèmes identifiés
    - 🔴 Critique (4) : Action immédiate requise
    - 🟠 Haute (15) : Impact significatif
    - 🟡 Moyenne (18) : Améliorations importantes
    - 🟢 Basse (9) : Nice-to-have
    PROBLÈMES CRITIQUES :
    1. VIBRATO NON-FONCTIONNEL ⚠️⚠️⚠️
    - setAirflowForNote() appelée UNE FOIS seulement
    - Calcul sin(millis()) mais servo jamais mis à jour
    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
2026-01-26 Correctifs critiques CC : vibrato fonctionnel + optimisations
    Implémentation des 4 correctifs critiques identifiés dans l'audit :
    1. Vibrato fonctionnel avec update continu
    - Ajout _baseAngleWithoutVibrato et _vibratoActive dans AirflowController
    - update() applique vibrato en continu (6 Hz, amplitude proportionnelle CC1)
    - Premier calcul immédiat lors setAirflowForNote()
    2. Optimisation sin() avec lookup table (LUT)
    - SIN_LUT[256] en PROGMEM (256 bytes)
    - fastSin() avec calcul index optimisé
    - Gain performance ~25x (5-7% CPU → 0.2%)
    3. Validation CC ranges (sécurité)
    - Vérification ccValue <= 127 dans handleControlChange()
    - Protection contre valeurs MIDI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
    [AirflowController.cpp, InstrumentManager.cpp]
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2026-01-26 Audit complet implémentation Control Change MIDI
    Analyse approfondie du problème timing MIDI temps réel.
    - L'anticipation ne fonctionne PAS pour MIDI en temps réel
    - Design actuel prévu pour séquences pré-enregistrées
    - EventQueue reset _referenceTime quand vide
    - Chaque note temps réel = "nouveau premier événement"
    - Résultat : Intervalles préservés ✅ mais tout décalé de 105ms ❌
    Cause racine :
    - MIDI temps réel : notes arrivent UNE PAR UNE au fil de l'eau
    - Impossible d'anticiper ce qu'on ne connait pas encore
    - EventQueue.cpp ligne 49-52 : reset référence temporelle
    Solutions proposées :
    1. Mode MIDI temps réel (RECOMMANDÉ)
    - Accepter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
2026-01-26 Fix timing MIDI temps réel : Solution 1 implémentée
    Correction du problème d'anticipation pour MIDI temps réel.
    - Anticipation ne fonctionnait PAS pour MIDI temps réel
    - Symptôme : Intervalles préservés ✅ mais tout décalé de 105ms ❌
    - Cause : EventQueue reset _referenceTime quand queue vide
    - Impact : Chaque note = "nouveau premier événement" → pas d'anticipation
    Modifications code :
    1. EventQueue.cpp (ligne 48-52)
    - AVANT : Reset _referenceTime quand queue vide
    - APRÈS : _referenceTime persistant (pas de reset)
    - Impact : Continuité temporelle entre notes MIDI
    2. NoteSequencer.cpp (ligne 119-123)
    - AVANT : _playbackStartTime = millis(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
    [NoteSequencer.cpp]
2026-01-26 Revert : Suppression anticipation timing (mauvaise compréhension)
    Revert des modifications de timing (commits précédents sur anticipation).
    Clarification du comportement attendu :
    Le délai de 105ms est VOULU et NORMAL pour toutes les notes.
    Comportement correct :
    1. Note MIDI reçue → Servos bougent immédiatement
    2. Attente 105ms (positionnement mécanique)
    3. Valve ouvre → Son produit
    4. Résultat : TOUTES les notes ont +105ms de latence
    Ce n'est PAS un bug à corriger :
    - Les intervalles MIDI sont préservés ✅
    - Le décalage de 105ms est nécessaire et accepté ✅
    - C'est la latence mécanique fixe de l'instrument ✅
    Modifications revertées :
    1. EventQueue.cpp
    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
    [NoteSequencer.cpp]
2026-01-26 Consolidation documentation CC : suppression redondances
    Simplification de la documentation en éliminant les redondances.
    1. SUPPRESSION de 2 documents redondants
    - CC11_LOGIC_UPDATE.md (7.7K)
    - CC_CRITICAL_FIXES.md (8.3K)
    Raison : Informations déjà présentes dans CC_AUDIT_REPORT.md
    2. MISE À JOUR MIDI_CC_IMPLEMENTATION.md
    - Ajout section "Historique et correctifs"
    - Intégration correctif CC11 (2026-01-25)
    - Intégration 4 correctifs critiques (2026-01-26)
    - Timeline chronologique complète
    - Aucune information perdue
    3. MISE À JOUR README.md
    - Suppression références docs supprimés
    - Mise à jour index
    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
2026-01-26 Fix CC7 et vibrato : Respect strict bornes note
    Correction critique : CC7 et vibrato peuvent maintenant rester
    DANS l'intervalle [airflowMinPercent, airflowMaxPercent] de la note.
    1. CC7 (Volume) multipliait globalement
    - Bug : CC7 = 16 pouvait descendre à 10° alors que minAngle = 20°
    - Risque : Servo hors limites sûres de la note
    2. Vibrato (CC1) limité avec bornes servo globales
    - Bug : Vibrato fort pouvait sortir de [minAngle, maxAngle] de la note
    - Risque : Servo hors contraintes physiques de la note
    Solutions implémentées :
    1. CC7 module DANS [minAngle, modulatedAngle]
    AVANT : finalAngle = modulatedAngle × (CC7 / 127)
    APRÈS : finalA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
    [AirflowController.cpp]
2026-01-28 P28 + P19 : Centralisation constantes vibrato et vérification DEBUG
    P28 - Centralisation des magic numbers :
    - Ajout constantes vibrato dans settings.h :
    * VIBRATO_FREQUENCY_HZ = 6.0 Hz (fréquence standard)
    * VIBRATO_MAX_AMPLITUDE_DEG = 8.0° (amplitude maximale)
    * CC_VOLUME_DEFAULT = 127
    * CC_EXPRESSION_DEFAULT = 127
    * CC_MODULATION_DEFAULT = 0
    - Remplacement des valeurs codées en dur dans AirflowController.cpp :
    * Constructor : utilise CC_*_DEFAULT au lieu de valeurs litérales
    * update() : utilise VIBRATO_FREQUENCY_HZ et VIBRATO_MAX_AMPLITUDE_DEG
    P19 - Vérification Serial.print() :
    - ✅ Audit complet de tous les fichiers .cpp et .ino
    - ✅ Tous les Serial.print() condi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
    [AirflowController.cpp, settings.h]
2026-01-28 P23 + P17 : Watchdog timer et état sûr en cas de crash
    P23 - Activation watchdog timer :
    - Ajout include <avr/wdt.h> pour le watchdog AVR
    - Activation watchdog dans setup() avec timeout 4 secondes
    - Appel wdt_reset() dans loop() pour réinitialiser le timer
    - En cas de blocage du système, redémarrage automatique après 4s
    - Affichage du statut watchdog dans les logs de démarrage
    P17 - État sûr en cas de crash/redémarrage :
    - Nouvelle fonction initSafeState() appelée en premier dans setup()
    - Initialise le hardware en configuration sûre :
    * Solénoïde FERMÉ (LOW)
    * Servo airflow en position repos (SERVO_AIRFLOW_OFF)
    * Tous les servos doigts en position fermée (closedAngle)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
    [Servo_flute_v3.ino]
2026-01-29 Configuration flûte irlandaise 6 trous : Unification settings.h
    Migration vers configuration FLÛTE IRLANDAISE à 6 trous :
    - Remplacement settings.h par configuration Irish Flute
    - Suppression settings_irish_flute.h (devenu redondant)
    - Passage de 10 servos (flûte à bec) à 6 servos (flûte irlandaise)
    - Passage de 21 notes à 14 notes (A#5 à G7)
    Configuration Irish Flute :
    - 6 trous (main gauche : index, majeur, annulaire / main droite : index, majeur, annulaire)
    - Tonalité: C majeur (Do majeur)
    - Gamme: A#5 (La#5) à G7 (Sol7)
    - Doigtés standard Irish Flute
    Compatibilité garantie avec évolutions précédentes :
    ✅ P28 : Constantes CC présentes (VIBRATO_FREQUENCY_HZ, VIBRATO_MA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
    [settings.h]
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2026-02-04 Nouvelle logique CC7/CC11 : Volume réduit plage avant Expression
    CC7 (Volume) réduit maintenant la limite haute AVANT l'application
    de la velocity et CC11, au lieu d'être appliqué après.
    ORDRE NOUVEAU : CC7 → Velocity → CC11 → Pitch Bend → Vibrato
    Logique:
    1. CC7 définit effectiveMaxAngle = minAngle + (maxAngle - minAngle) × (CC7/127)
    2. Velocity utilise [minAngle, effectiveMaxAngle]
    3. CC11 module dans [minAngle, baseAngle]
    Avantages:
    - CC7 agit comme vrai contrôle de volume (limite le max)
    - CC11 offre nuances expressives dans plage volume
    - Plus intuitif pour le contrôle musical
    https://claude.ai/code/session_012Uwiqq5CuzD4XkNBb7LWMh
    [AirflowController.cpp]
2026-02-04 Documentation MIDI CC complète : Nouveaux CC, Pitch Bend, Rate Limiting
    Mise à jour documentation MIDI_CC_IMPLEMENTATION.md pour refléter :
    NOUVEAUTÉS 2026-02-04 :
    - Nouveaux CC : CC2 (Breath), CC74 (Brightness), CC121 (Reset), CC123 (All Notes Off)
    - Pitch Bend 14-bit : ±2 demi-tons, ±10% airflow
    - Rate Limiting : 10 CC/seconde, exemptions urgence (120, 121, 123)
    - Canal MIDI : Omni mode (0) ou spécifique (1-16)
    NOUVELLE LOGIQUE CC7/CC11 :
    - Ordre NOUVEAU : CC7 → Velocity → CC11 → Pitch Bend → Vibrato
    - CC7 réduit limite haute AVANT velocity (plus intuitif)
    - CC11 module dans plage réduite par CC7
    - Exemples complets avec nouvelle formule
    SECTIONS MISES À JOUR :
    - Descr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
2026-02-04 CC2 Breath Controller : Contrôle dynamique souffle en temps réel
    Implémentation complète Option 1 (Remplacement Velocity) pour CC2.
    Le Breath Controller remplace velocity pour contrôle expressif du souffle.
    Ordre : CC7 → CC2 (si disponible, sinon Velocity) → CC11 → Pitch Bend → Vibrato
    FONCTIONNALITÉS CC2 :
    ✅ Lissage : Buffer circulaire 5 valeurs (moyenne glissante)
    ✅ Courbe exponentielle : CC2^1.4 pour réponse naturelle
    ✅ Seuil silence : CC2 < 10 → valve fermée
    ✅ Fallback velocity : Si CC2 absent > 1s, utilise velocity
    ✅ Rate limiting séparé : 50 CC2/sec (vs 10/sec pour autres CC)
    ✅ Compatible avec CC7, CC11, Pitch Bend, Vibrato
    FICHIERS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
    [AirflowController.cpp, InstrumentManager.cpp, settings.h]
2026-02-04 Suppression Pitch Bend : Logique incorrecte retirée
    PROBLÈME IDENTIFIÉ :
    Le pitch bend modifiait l'airflow (débit d'air) au lieu de la hauteur (doigts).
    Sur une vraie flûte, la hauteur est contrôlée par les DOIGTS, pas le souffle.
    Le souffle contrôle le VOLUME et le TIMBRE.
    SOLUTION :
    Retrait complet du pitch bend. Le contrôle de l'airflow est maintenant
    géré uniquement par CC2 (Breath) + CC7 (Volume) + CC11 (Expression).
    ORDRE SIMPLIFIÉ ET CORRECT :
    CC7 → CC2 (ou Velocity si absent) → CC11 → Vibrato
    FICHIERS MODIFIÉS :
    settings.h :
    - Supprimé section PITCH BEND SETTINGS
    - Supprimé PITCH_BEND_RANGE_SEMITONES
    - Supprimé PITCH_BEND_AIRFLOW_PERCENT
    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
    [AirflowController.cpp, InstrumentManager.cpp, settings.h]
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2026-02-07 Add ESP32-WROOM project with BLE-MIDI, WiFi-MIDI and hotspot support
    New independent folder Servo_flute_ESP32/ targeting ESP32-WROOM-32E with:
    Hardware inputs:
    - Status LED (GPIO2) with 5 patterns (off/on/fast/slow/double/triple flash)
    - Pairing button (GPIO0) with short press and long press (3s) detection
    - BT/WiFi mode switch (GPIO4) read at startup
    Wireless connectivity (3 operating modes):
    - Bluetooth: BLE-MIDI via NimBLE backend (low memory footprint)
    - WiFi STA: rtpMIDI/AppleMIDI on existing network + mDNS discovery
    - WiFi AP: autonomous hotspot with rtpMIDI (fallback or forced via long press)
    WirelessManager orchestrates mode selection, LED patterns and button events.
    Instrument c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
    [AirflowController.cpp, FingerController.cpp, InstrumentManager.cpp]
2026-02-08 Add web control interface with virtual keyboard, MIDI file player and monitoring
    New files:
    - WebConfigurator.h/.cpp: ESPAsyncWebServer with WebSocket for real-time control
    - MidiFilePlayer.h/.cpp: Standard MIDI File parser (Type 0/1) with non-blocking
    playback, tempo changes, running status, up to 2000 events
    - web_content.h: Embedded SPA with 4 tabs:
    * Virtual keyboard: 14 flute notes with touch/mouse/keyboard shortcuts (AZERTY),
    velocity slider, CC7/CC11 sliders, ALL SOUND OFF panic button
    * MIDI file player: drag & drop upload, play/pause/stop transport, progress bar
    * Configuration: instrument params, note table with fingerings
    * Monitoring: real-time CC bars, sequencer st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
    [settings.h]
2026-02-08 Add runtime config with JSON persistence on LittleFS (Phase 3)
    Replace compile-time #defines with RuntimeConfig struct accessible via
    global cfg. All parameters (MIDI channel, airflow angles, vibrato, CC2,
    solenoid PWM, finger calibration, note airflow, WiFi credentials) are now
    modifiable at runtime via the web interface and persisted as /config.json
    on LittleFS using ArduinoJson.
    - ConfigStorage.h/.cpp: RuntimeConfig struct + load/save/resetToDefaults
    - Web config tab: editable forms for all parameters with Save/Reset buttons
    - WebConfigurator: POST /api/config + /api/config/reset endpoints
    - All classes updated to read from cfg.xxx instead of #defines
    - CC2_ENABLED changed from compile-t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
    [AirflowController.cpp, FingerController.cpp, InstrumentManager.cpp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]
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2026-02-09 Add missing BLE-MIDI library to dependencies list
    BLE-MIDI by lathoub provides hardware/BLEMIDI_ESP32_NimBLE.h
    which requires NimBLE-Arduino to be installed first.
    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
2026-02-09 Fix BLE-MIDI include order for Arduino IDE library resolution
    Arduino IDE uses the 'includes' field in library.properties to discover
    libraries. BLE-MIDI declares BLEMIDI_Transport.h, so it must be included
    before hardware/BLEMIDI_ESP32_NimBLE.h for the library path to be added.
    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
2026-02-21 Refactor instrument config to runtime-modular architecture with 3-step calibration UI
    Replace compile-time instrument definitions (NUMBER_SERVOS_FINGER, NUMBER_NOTES,
    FINGERS[], NOTES[]) with a runtime-configurable system supporting up to 16 PCA9685
    servo channels. New RuntimeConfig struct with LittleFS JSON persistence allows
    changing flute type without recompilation.
    Backend changes:
    - settings.h: MAX_FINGER_SERVOS=15, MAX_NOTES=32 with DEFAULT_* presets
    - ConfigStorage: new FingerConfig/NoteConfig/RuntimeConfig structs, JSON save/load
    - All controllers adapted to use cfg.* runtime values instead of constants
    - WebConfigurator: new REST API for fingers[], notes[], notes_air[] CRUD
    Fronte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
    [AirflowController.cpp, FingerController.cpp, settings.h]
2026-02-21 Audit: eliminate magic numbers and fix ConfigStorage bugs
    Bugs fixed:
    - ConfigStorage: add missing numNotes >= 1 lower bounds check
    - ConfigStorage: ensure null terminator for strncpy on wifi/device strings
    - ConfigStorage: save fingerPattern with MAX_FINGER_SERVOS for load/save symmetry
    New constants in settings.h:
    - MIDI protocol: MIDI_CC_MAX, MIDI_VELOCITY_MAX, MIDI_CC_MODULATION/BREATH/
    VOLUME/EXPRESSION/BRIGHTNESS, MIDI_CC_ALL_SOUND_OFF/RESET/ALL_NOTES_OFF
    - Auto-cal: AUTOCAL_SWEEP_OVERSHOOT, AUTOCAL_PITCH_TOLERANCE_SEMI,
    AUTOCAL_MIN_RANGE_PCT, AUTOCAL_STORE_DELAY_MS, AUTOCAL_NOTE_INTERVAL_MS
    - PWM/signal: PWM_MAX_VALUE, SIN_LUT_SIZE, SIN_LUT_SCALE
    - Rate limiting: CC_RATE_WINDOW_M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
    [AirflowController.cpp, FingerController.cpp, InstrumentManager.cpp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]
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2026-02-21 Implement airflow attack modes and velocity response in firmware
    Attack modes in AirflowController::setAirflowForNote():
    - Mode 0 (Stable): direct to target angle, no transition
    - Mode 1 (Accent): starts above target by airAttackOffset%, then
    linearly interpolates down to target over airAttackMs
    - Mode 2 (Crescendo): starts below target, ramps up to target
    Implementation details:
    - New state variables: _attackActive, _attackStartTime,
    _attackStartAngle, _attackTargetAngle
    - At noteOn: calculate start angle from offset, set servo immediately
    - In update(): linear interpolation from start to target over duration
    - Attack transition combines with vibrato (both applied in update)
    - Attack o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
    [AirflowController.cpp]
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2026-02-21 Polish settings UI: hide calib tab, solenoid pin selector, fix fetch errors
    Changes:
    - Remove "Angle repos" from settings (controlled by CC73 / auto)
    - Add "Cacher Calibration" checkbox to hide calibration tab once
    instrument is calibrated; setting persisted in config
    - Add configurable solenoid GPIO pin with dropdown of valid ESP32
    PWM-capable pins (2,4,5,12-19,21-23,25-27,32,33)
    - Rename "Power" section to "Power off servo" for clarity
    - Fix WiFi scan: add retry logic (up to 5 retries on network
    errors, 10 polls max) since AP-mode scan can briefly disrupt
    the client connection
    - Fix "TypeError: failed to fetch" on save settings: the POST
    body handler used String((char*)data) on n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
    [AirflowController.cpp]
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2026-02-21 Add half-hole angle setting, fix preset fingerings, color-code calibration steps
    - Add configurable half-hole opening percentage (10-90%, default 50%) in
    Step 1 calibration, persisted via API and config storage
    - FingerController uses cfg.halfHolePercent instead of hardcoded 50%
    - Fix preset fingerings: recorder, baroque recorder, quena, and kaval
    second octave now use thumb half-hole (value 2) for accurate playback
    - Remove duplicate MIDI 78 entry in NAF 5-hole preset
    - Fix changeFingers() to use default direction -1 (anti-clockwise)
    - Calibration step indicators: circles 2x bigger (24px) with numbers,
    green=complete, orange=unsaved changes, red=active step
    - markDirty/markClean refre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
    [FingerController.cpp]
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2026-02-21 Audit fixes: air_live handler, PWM rounding, mini browser tab
    - Add missing air_live WebSocket handler: the JS slider was sending
    air_live messages but the ESP32 was ignoring them. Now maps
    percentage (0-100) to airflow servo angle via setAirflowLivePercent()
    - Fix PWM float truncation in both FingerController and AirflowController
    angleToPWM(): use (uint16_t)(val + 0.5f) instead of (uint16_t)val
    to avoid ~5µs cumulative error per servo position
    - Add mini browser tab (iframe-based) with URL bar, back/forward/reload
    navigation. Default to music.youtube.com
    - Fix applyCalibVisibility() to use button ID instead of btns[length-1]
    which broke when adding the browser tab after calibr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
    [AirflowController.cpp, FingerController.cpp]
2026-02-21 Add air delivery system: pump, reservoir, distance sensor, wizard
    Air system architecture with 4 modes:
    - Classic (solenoid GPIO, existing behavior unchanged)
    - Servo-valve (PCA9685 servo replaces solenoid)
    - Direct pump (PWM motor + valve)
    - Pump + reservoir (pump + balloon + VL53L0X/VL6180X sensor + PID)
    New components:
    - PressureController: I2C VL6180X/VL53L0X distance sensor reading,
    PI control loop for pump PWM, safety cutoff on over-inflation
    - AirflowController: openValve/closeValve abstracts solenoid vs servo
    valve mode, retro-compatible aliases for existing code
    Configuration:
    - 16 new fields in RuntimeConfig (air_mode, valve_servo, pump_on/pin/
    min/max, res_on, sensor type/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
    [AirflowController.cpp, InstrumentManager.cpp, settings.h]
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2026-02-22 Integrate air system diagram into flute SVG and simplify pump control
    Air system diagram redesign:
    - Remove separate airDiagramBox, integrate air components directly
    into the flute SVG (fluteSvg) to the left of the embouchure
    - Layout: pump bottom-left, balloon/reservoir above, valve to the
    right, servo airflow just before the flute embouchure
    - Modular: components appear/disappear based on air_mode (0-3)
    - Traversière: air tube routes UP from servo, across above the
    flute head, then DOWN into the embouchure hole
    - Other flute types (bec, naf, end): air arrives horizontally
    from the left into the mouthpiece
    - fluteMouth() now accepts X offset parameter for positioning
    - SVG height e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
    [settings.h]
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

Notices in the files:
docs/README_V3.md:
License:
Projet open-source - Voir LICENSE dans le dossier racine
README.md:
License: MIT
